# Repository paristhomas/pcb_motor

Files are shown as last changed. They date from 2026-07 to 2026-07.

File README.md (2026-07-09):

# pcb_motor

**Design coreless axial-flux PCB motors — concept to fab-ready Gerbers.**

A coreless axial-flux motor where the stator is a PCB: copper spirals replace wound
wire, the board house replaces the winding shop, and the rotor is disc magnets glued to
a carrier. This repo takes you from "roughly this much torque in roughly this much
space" to a Gerber zip you can upload to a fab — via an analytical physics engine, a
production coil-artwork generator, and a report generator.

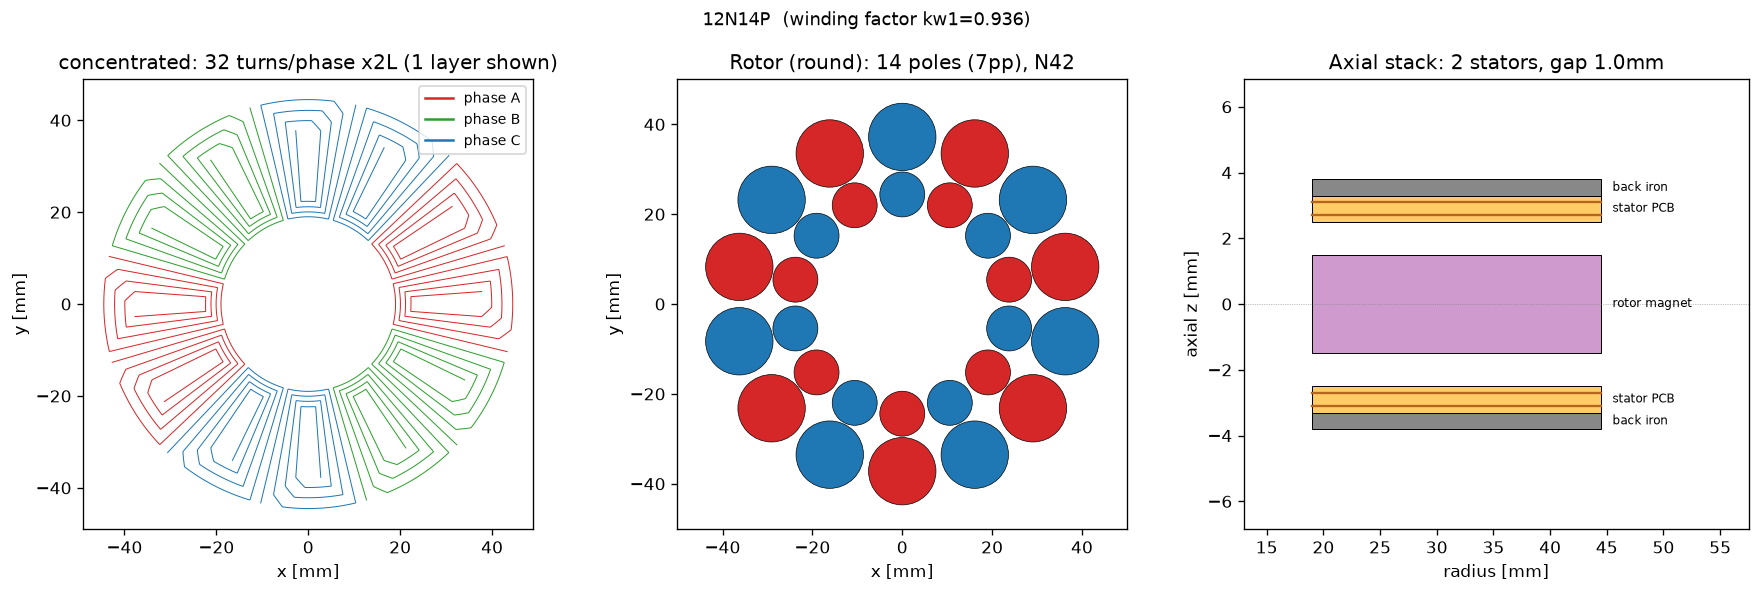
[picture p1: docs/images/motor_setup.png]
Motor setup: winding, rotor, and axial stack


Under the hood: a vectorized Biot–Savart field solver on the actual copper geometry,
Amperian current-loop magnets, proper 3-phase commutation, a coil-artwork generator that
emits production KiCad footprints with net-bearing terminal pads, a board generator that
wraps them into a complete `.kicad_pcb`, and a `kicad-cli` step that plots fab-ready
Gerbers.

## Start here: drive it with an LLM agent

**The intended way to use this repo is to point a coding agent at it and talk to it in
plain language — not to memorize the CLI.** The repo ships a Claude skill
(`.claude/skills/pcb-motor-design`) that turns your requirements into a finished design.

1. Install [Claude Code](https://claude.com/claude-code): `npm i -g @anthropic-ai/claude-code`
   (or use any LLM coding agent — Cursor, the Claude/ChatGPT desktop apps with repo access, etc.).
2. Clone this repo and do the [one-time install](#install) below (`.venv` + `pip install -e .`).
3. From the repo root, launch the agent (`claude`) and just describe the motor you want:

> "design me a pancake motor for a camera gimbal, about 50 mNm continuous, 80 mm max
> diameter, 24 V bus"

The skill auto-loads and the agent captures the requirements, seeds a design, iterates it
against your envelope, runs the feasibility gates, and produces the KiCad files, Gerbers,
and an HTML report — asking you to confirm along the way. You never have to learn the
commands yourself; the agent runs them. [docs/design_guide.md](docs/design_guide.md) is
the full stage-by-stage walkthrough; the rest of this README is the short version for
when you *do* want to drive the CLI by hand.

## Install

```bash
python3 -m venv .venv
.venv/bin/pip install -e ".[dev]"
source .venv/bin/activate
```

Core deps: numpy, scipy, matplotlib, pyyaml, shapely. The optional `[sweep]` extra adds
`holobench` for interactive parameter-sweep dashboards and optuna search. Exporting
Gerbers additionally needs **KiCad ≥ 7** on the machine (the `kicad-cli` it ships); the
tool auto-detects a native install or a Windows KiCad reachable from WSL.

## The five-minute tour

Every design lives in a *session* — a directory under `designs/<name>/` holding the
saved motor plus everything you generate for it. Seed one from defaults (a 60 mm-class
12-slot / 14-pole twin-stator machine) and it evaluates immediately:

```text
$ pcb-motor new --session my-first-motor
session saved to designs/my-first-motor
requirements skeleton written to designs/my-first-motor/requirements.yaml -- fill in your targets (torque, speed, voltage, envelope, duty)
pcb-motor point  [concentrated, 7pp, N42, 2 stator(s)]
--------------------------------------------------------
  Continuous acceleration             583.1 rad/s^2
  Continuous torque                   15.39 mNm
  Kt (torque constant)                48.48 mNm/A
  Continuous current                 0.3175 A
  Mean airgap |Bz|                   0.1823 T
  ...
  Phase inductance (air-core)         76.86 uH
  PWM ripple @bus/fsw                 1.626 A pp
  Ext. L for ripple budget             1235 uH
  ...
  Winding factor kw1                 0.9393

!!!!!!!!!!!!!!!!!!!!!!!!!!!!!!!!!!!!!!!!!!!!!!!!!!!!!!!!
WARNINGS (1):
  ! PWM ripple 1.63 A pp exceeds the 0.10 A budget (17x) at 12 V bus / 24 kHz / 30% of I_cont: not drivable without ~1235 uH/phase external inductance -- see design guide Stage 5.
!!!!!!!!!!!!!!!!!!!!!!!!!!!!!!!!!!!!!!!!!!!!!!!!!!!!!!!!
```

The skeleton `requirements.yaml` holds your torque/speed/voltage/envelope/duty targets,
so the design and its requirements travel together. The wall of exclamation marks is the
no-choke feasibility gate: air-core PCB windings have very little inductance, so most
small designs need a series choke to run from a PWM drive. The gate reports that now
rather than after boards are ordered (design guide Stage 5 is entirely about this).

`--set` overrides any `MotorDesign` field on top of the saved session, and
`pcb-motor fields` prints every settable field, grouped, with its default and meaning:

```text
$ pcb-motor point --session my-first-motor --set trace_width_m=0.2e-3
pcb-motor point  [concentrated, 7pp, N42, 2 stator(s)]
--------------------------------------------------------
  Continuous acceleration             622.8 rad/s^2
  Continuous torque                   16.44 mNm
  ...
```

Then generate the deliverables:

```text
$ pcb-motor report --session my-first-motor
design report written to designs/my-first-motor/design_report.html

$ pcb-motor datasheet --session my-first-motor
datasheet written to designs/my-first-motor/datasheet.md

$ pcb-motor footprint --session my-first-motor
footprint written to designs/my-first-motor/stator_full_2side.kicad_mod (PASS, ...)

$ pcb-motor board --session my-first-motor --gerbers
board written to designs/my-first-motor/kicad_board (PASS)
SUMMARY: PASS  (12 files, zip pcb_motor_stator_gerbers.zip)  kicad-cli 9.0.7
```

`footprint` builds the production two-sided filled-copper stator footprint — net-bearing
terminal pads, via stitch, clearance-verified against JLC rules *before* it writes.
`board` wraps that footprint in a complete `.kicad_pcb` (board outline, bore, WYE nets),
and `--gerbers` plots the fab-ready Gerber + drill set and zips it. For the general
board path the coil copper plots as filled polygons and the cross-ring phase
interconnect is left as a ratsnest for you to route in KiCad — the board is
manufacturable, and that last routing step is the one thing the tool leaves to you.
(The `export` command is a quick `fp_line` artwork preview for eyeballing in KiCad.)

Rounding out the CLI: `config` (setup figure), `showcase` (the shareable single-file
story page — see below), `compare` (sessions side by side), and `sweep` / `optimize`
(interactive dashboards and optuna, with the `[sweep]` extra).

Here's the fabricated 12N14P winding the engine generated, and the Biot–Savart field its
rotor puts through the stator plane:

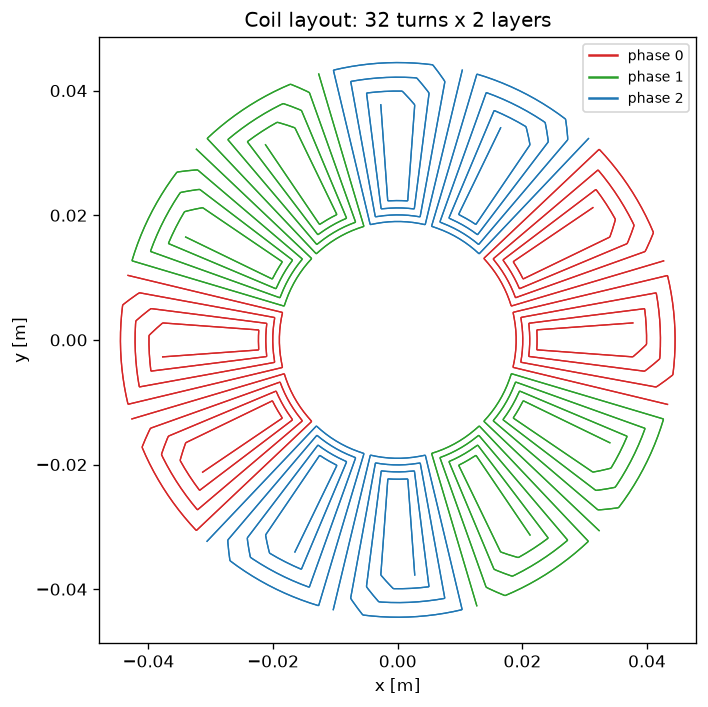
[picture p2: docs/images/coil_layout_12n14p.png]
12N14P coil layout


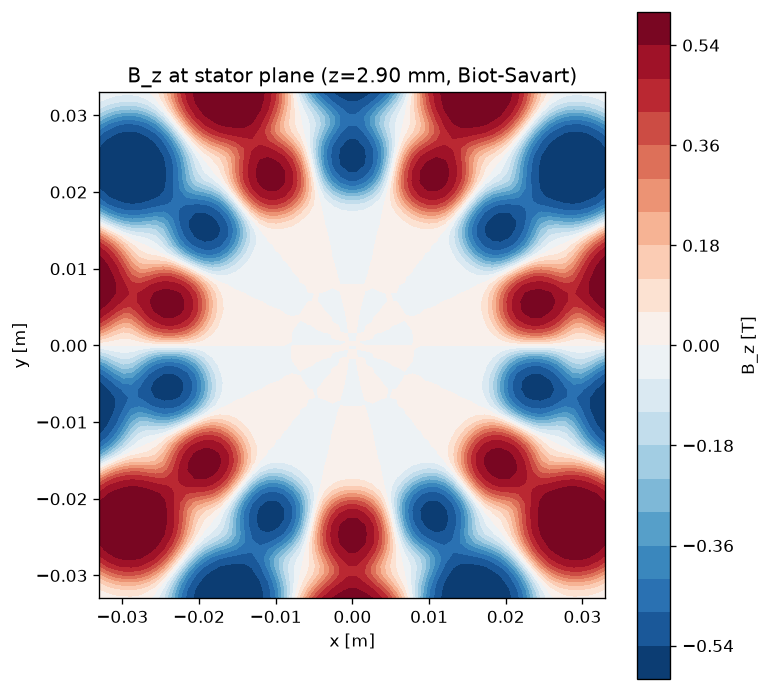
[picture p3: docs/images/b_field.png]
Airgap B_z field at the stator plane


## What you get

- **Coil artwork** — `.kicad_mod` footprints of the real winding. The production builder
  (`pcb_motor.kicad.build_footprint`) emits two-sided filled-copper artwork with
  net-bearing terminal pads, mirrored back-layer copper (so the two layers add torque
  rather than cancel it), a via stitch between layers, and in-footprint series bridges.
  It shapely-verifies every clearance against JLC 1 oz rules before writing and refuses
  to emit a failing board.
- **A complete KiCad board** — `pcb_motor.kicad.build_board` wraps the footprint in a
  full `.kicad_pcb` (board outline, bore, mounting holes, WYE nets bound to the terminal
  pads), alongside the symbol library and pre-wired 3-phase schematic from
  `build_kicad_project`. The fabricated board (dualstator90-12n14p) additionally ships a
  verbatim fully-routed board.
- **Fab-ready Gerbers** — `pcb_motor.kicad.export_gerbers` runs `kicad-cli` to plot the
  standard 2-layer set (copper, mask, silkscreen, paste, edge cuts) plus an Excellon
  drill file, and zips it for upload.
- **An HTML design report and Markdown datasheet** — every headline number plus the
  setup figures and a self-contained showcase page.
- **Honest feasibility numbers** — thermal continuous current, drive voltage at that
  current, current density, airgap shear, rotor inertia, and the no-choke drive gate:
  worst-case PWM current ripple (`v_bus / (4·L·f_pwm)`) and the external inductance
  needed to hit your ripple budget. Most small PCB motors need that choke.

## The main event: the board that was fabricated

[`examples/dualstator90-12n14p/`](examples/dualstator90-12n14p/) (shipped as *gimbal90*) is
a real 90 mm 12N14P dual-stator stator that was **actually fabricated** — this is the
board the whole repo exists to reproduce. It is a fully-routed board (every coil link, WYE
star and phase lead baked into copper), with back iron, M3 mounting tabs and PTH terminals.
`pcb-motor board --session dualstator90-12n14p --gerbers` regenerates it and plots its
Gerbers; the regenerated board is coordinate-for-coordinate identical to the manufactured
one in [`examples/dualstator90-12n14p/fabricated/`](examples/dualstator90-12n14p/fabricated/)
and the Gerbers match it layer-for-layer (see `tests/test_board_fabequiv.py`).

The best way to meet it is the **showcase report** — one self-contained HTML page from
`pcb-motor showcase`: the rotor spinning over the real copper with the Biot–Savart field,
the zoomable board artwork with its real outline and mounting tabs, the exploded stack, the
trace-width trade charts, and the drive-gate verdict in large print.

## Generalization evals (proof it isn't over-fit to that one board)

Two further sessions exist only to show the same concept→board→Gerber workflow holds for
*different* machines, driven the same way:

- [`examples/dualstator80-36n42p/`](examples/dualstator80-36n42p/) — an 80 mm, 42-pole
  dual-stator pancake (off-the-shelf round disc magnets). The tool's honest verdict:
  **20.5 mNm continuous (±30%)**, and *driving it choke-free from an ODrive is infeasible by
  32× — budget ~204 µH per phase.* It reports the "no" instead of hiding it.
- [`examples/dualstator140-24n28p/`](examples/dualstator140-24n28p/) — a 140 mm 24N28P
  machine an **independent agent** designed end-to-end from only a brief and the skill.

## The physics, honestly

> This is an **analytical, feasibility-grade model: treat absolute torque as ±30%.**
> The field solver itself is validated to <1% against closed-form solutions — the error
> budget is dominated by what the model *doesn't* capture: magnet Br tolerance and
> fringing, your actual assembled air gap (the single most sensitive parameter, and the
> one your 3D-printed parts control), and etching/plating variation in the copper.
> Relative comparisons between designs are much better than ±30%. Calibrate against FEMM
> or a bench coil before you commit money to a build. Details and validation notes in
> [docs/physics.md](docs/physics.md).

Limitations, stated up front:

- **No magnetic saturation modeling.** Fine for coreless (air doesn't saturate); the
  optional back-iron model is method-of-images with µ→∞ plates — a *sanity flag*, not a
  design tool, and it ignores eddy/hysteresis drag in the plate.
- **Thermal model is a lumped convection balance** (`h·A·ΔT`) with an assumed film
  coefficient — good for "is this thermally plausible", not for hot-spot prediction.
- **Inductance is ±20%** (Neumann double sum) — right for "do I need a choke", wrong for
  filter design.
- **Dual-rotor axial attraction is reported as a warning, not a number.** Two magnet
  disks facing each other pull hard; size the spacer, hub, and assembly jig for it.
- No cogging (coreless — there is none), no acoustic, no bearing model, no FEA.

## Docs

- [docs/design_guide.md](docs/design_guide.md) — the full walkthrough: requirements →
  seed → evaluate → iterate → feasibility gate → KiCad board → Gerbers → fab notes.
- [docs/physics.md](docs/physics.md) — how the model works and where it approximates.
- [docs/jlc_design_rules.md](docs/jlc_design_rules.md) — JLCPCB rules and IPC
  current-capacity numbers the coil generator designs against.

Housekeeping: `designs/` is a working area (gitignored) where your sessions land;
`examples/` holds the committed, published designs.

## Acknowledgements

The Biot–Savart field solver (`pcb_motor/field.py`) is an independent NumPy
reimplementation cross-validated against the "Biot-Savart Magnetic Field Calculator" by
Mingde Yin and Ryan Zazo.

## License

MIT — see [LICENSE](LICENSE).

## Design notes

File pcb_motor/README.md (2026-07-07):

# pcb_motor — Biot–Savart coreless axial-flux PCB-motor engine

For a given stator/rotor configuration, evaluate (and optimise) the PCB
stator-coil design directly from copper geometry, *simulating* the magnetics
numerically (Biot–Savart). Reports Kt, torque, air-gap field, winding factor,
thermal continuous rating, current density, shear, rotor inertia, and
continuous acceleration `a_cont = τ_cont / J` — enough to judge a design against
real requirements (torque, voltage, size, duty), not just one objective.

Self-contained: all physical constants live in `constants.py`.

## Install / run

```bash
python3 -m venv .venv && .venv/bin/pip install -e ".[dev]"
.venv/bin/python -m pcb_motor point                       # evaluate one design
.venv/bin/python -m pcb_motor config --out setup.png      # winding + rotor + stack figure
.venv/bin/python -m pcb_motor sweep --inputs trace_width_mm,trace_space_mm --serve
.venv/bin/python -m pcb_motor optimize --trials 100       # max continuous accel
.venv/bin/python -m pytest -q
```
`point` needs only the core deps; `sweep`/`optimize` need `holobench`
(`pip install -e ".[sweep]"`).

## Model (and its limits — this is a ~±30% feasibility-grade model)

- **Field** (`field.py`): vectorised numpy Biot–Savart kernel. Validated to <1%
  against the closed-form on-axis loop field (`tests/test_field.py`).
- **Magnets** (`magnets.py`): Amperian current-loop model, `I_eq = (Br/μ0)·t`,
  alternating polarity. Rotor topologies via `magnet_topology`:
  `"arc"` (continuous pole-arc ring); `"round"` (two concentric rings of round
  disc magnets — inner+outer of each pole share polarity; the buildable round-stock
  rotor); and the single-ring study variants `"round_outer"` (outer ring of larger
  discs only) and `"round_inner"` (inner ring of smaller discs only). Inertia
  (`inertia.py`) and the carrier extent are topology-aware (they key off
  `magnets.active_rings`), so the acceleration objective fairly reflects each
  rotor's magnet mass. Perimeter/thin-shell approximation.
- **Coils** (`coils.py`): default **`concentrated`** — `n_slots` discrete
  multi-turn **wedge-spiral** coils (default 12 slots / 14 poles = 12N14P). Turns
  nest inward by one trace pitch on all sides, so no copper overlaps (fabricable,
  KiCad-exportable). Phase + polarity per tooth come from the **star-of-slots**
  layout (12N14P: order A,C,B in opposite-polarity pairs). `winding_factor()`
  returns kw1 (~0.93 for 12N14P). Alternatives: `radial_spoke`, `spiral`.
- **Torque** (`torque.py`): field evaluated on a coarse polar grid per rotor
  angle/layer and interpolated onto the coil (decouples cost from mesh density).
  Kt uses **proper 3-phase commutation** — sinusoidal currents synchronised to the
  rotor at the optimal commutation angle — so the **winding factor is folded into
  Kt physically** (no hand-applied kw). Reports `winding_factor` (analytic kw1) and
  `winding_utilisation` (commutated/ideal-abs-sum).
- **Back iron** (`iron.py`): optional flat plate behind each stator, modelled by
  the method of images (μ→∞ planes). Sanity-grade: no saturation, no plate
  eddy/hysteresis drag; the per-plate magnetic pull is reported so the mechanics
  can be sized for it.
- **Continuous torque/accel**: `τ_cont = Kt·I_cont`, `I_cont` from the thermal
  model (`thermal.py`), `J` from `inertia.py`.
- **Parasitics** (`parasitics.py`): air-core phase inductance (Neumann double
  sum, ~±20%), worst-case (D=0.5) PWM current ripple
  `ripple_pp = v_bus/(4·L·f_pwm)` — the "do I need a choke" feasibility gate —
  and an eddy-loss screen for wide traces at speed.

Key caveat: `current_density` is reported as a sanity flag, not enforced, and
absolute numbers everywhere are feasibility-grade (~±30%), never bench-exact.

## Exploring the design space

Sweep any 1–3 `MotorDesign` axes interactively (needs `holobench`); open the
printed `http://localhost:9001`:

```bash
.venv/bin/python -m pcb_motor sweep \
  --inputs trace_width_mm,magnet_topology \
  --results accel_cont,tau_cont,kt,j_rotor,b_gap_mean,copper_mass \
  --serve --port 9001
```

Key reading: `accel_cont` is magnet-fill-insensitive on a bare rotor (torque and
inertia both scale with magnet mass and cancel); compare rotors on `kt` /
`tau_cont` / `b_gap_mean`, or on acceleration *with a load inertia*
(`--set load_inertia_kgm2=…`).

## Layout
`design.py` (contracts) · `field.py` · `magnets.py` · `coils.py` · `torque.py` ·
`iron.py` · `parasitics.py` · `thermal.py` · `inertia.py` · `evaluate.py`
(design→results) · `sweep.py` (bencher) · `viz.py` · `cli.py` · `kicad/`
(footprint/project export). See `interfaces.md` for the module APIs.

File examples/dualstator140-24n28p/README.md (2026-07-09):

# dualstator140-24n28p — the generalization eval (designed by an independent agent)

This design exists to answer one question: **is the `pcb_motor` workflow actually
general, or is it secretly tuned for the dualstator90-12n14p board it was built around?**

To test that honestly, a **fresh agent** — given only an application brief, this repo,
and the `pcb-motor-design` skill, and *none* of the authoring context — drove the entire
workflow itself, in one shot, on the first run, with zero tool fixes. What's here is what
it produced, **untouched except for one later change made at the maintainer's explicit
request: a third magnet ring** (see "Maintainer enhancement" below). Everything else —
the 24N28P winding, the board, the Gerbers, the honest gate failure — is exactly the
agent's one-shot output.

## The brief it was given

> A pancake BLDC motor for a lightweight camera slider / pan-head direct drive.
> Outer diameter ≤ 140 mm, thin stack; maximize continuous torque at the thermal limit
> (40–60 mNm would be great); ODrive, 24 V bus; dual-stator / single-rotor, no back iron;
> two 2-layer 0.8 mm FR4 JLCPCB boards (1 oz, 5/5 mil); off-the-shelf round disc magnets.

## What the agent chose (and why)

- **24N28P** (24 slots, 14 pole-pairs), verified **kw1 = 0.9374** — a genuinely different
  machine from dualstator90-12n14p (12N14P, 90 mm). It compared three pole counts head-to-head and
  found that with *round-disc* magnets the largest combo (36N42P) is actually the worst,
  because disc packing forces smaller magnets and collapses the airgap field — the round
  magnet constraint inverts the usual "more poles → more torque" intuition.
- **134 mm copper OD** (138 mm board edge, inside the 140 mm limit), 60 mm bore, N52 discs
  in **two concentric rings**, tapered-wedge traces, 0.6 mm neck / 0.127 mm space.

## Maintainer enhancement — a third magnet ring

The agent shipped a **two-ring** rotor (that is what the eval recorded). Afterwards, at
the maintainer's explicit request, this repo grew a general `round3` topology (a middle
ring of discs per pole) and applied it here — **the single deviation from the agent's
one-shot design.** The three rings step **up in size going outward** — inner **Ø8 @ 40 mm**,
middle **Ø9 @ 49.5 mm**, outer **Ø12 @ 61 mm** (the outer ring nudged out from the agent's
58 mm to make room, its edge now at the 67 mm coil OD). Filling the previously-empty middle
band — full of current-carrying copper but no field — lifts continuous torque **+32.6%**
(142 → **188 mN·m**, Kt 97 → **129 mN·m/A**) for the same winding, current and copper. Every
disc keeps **≥0.8 mm of carrier** to its neighbours (tightest is the inner ring at 0.98 mm
pole-to-pole; the engine warns below 0.8 mm). This is a *documented change to the artifact*,
not part of the blind eval; the two-ring numbers above are what the agent produced on its own.

## What it delivered (all PASS)

| Artifact | File |
|---|---|
| Production footprint (clearance-verified) | `stator_full_2side.kicad_mod` |
| Complete board | `kicad_board/pcb_motor_stator.kicad_pcb` |
| Fab-ready Gerbers (12 files + drill) | `kicad_board/pcb_motor_stator_gerbers.zip` |
| Showcase report | `report.html` |
| Datasheet / design | `datasheet.md`, `motor.json`, `requirements.yaml` |

Headline numbers (analytical, **±30%** — calibrate against FEMM / a bench coil before
spending money), **with the three-ring rotor**: **Kt ≈ 129 mNm/A, ~188 mNm continuous**
at 1.46 A / 6.0 Ω, drive voltage 11.6 V (comfortable under the 24 V bus), kw1 0.9374,
airgap |Bz| ≈ 0.13 T. (The agent's original two-ring rotor: Kt ≈ 97 mNm/A, ~142 mNm,
|Bz| ≈ 0.10 T.)

## The honest verdict

The no-choke drive gate **fails, on purpose and out loud**: 7.2 A pp ripple vs a 0.44 A
budget — **16× over** at 24 V / 24 kHz. Air-core PCB windings are µH-class (L ≈ 35 µH), so
this needs a **~536 µH/phase series choke** (rated ≥ 1.5 A) to run from a bare ODrive.
The agent reported this rather than dialling knobs to fake a pass — which is exactly the
behaviour the tool is built to produce.

As with the general board path, the cross-ring phase interconnect (9 joins) is left as a
**ratsnest** for a human to route in KiCad; the board is otherwise complete and
manufacturable.

**Bottom line:** an independent agent took the workflow from a bare application brief to
a fab-ready board + Gerbers + report, on the first run, with no author intervention. The
workflow generalizes.

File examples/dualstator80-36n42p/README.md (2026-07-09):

# dualstator80-36n42p — an 80 mm no-choke attempt, honestly lost

This directory is a complete, committed design session: what the tool was asked for,
what it designed, and what it said about the result — including the part the brief
didn't want to hear. Everything here was produced by `pcb-motor` commands against
this repo; nothing is retouched. All absolute numbers carry the model's honesty band:
**±30% on torque** (see [docs/physics.md](../../docs/physics.md)).

## The brief

From [`requirements.yaml`](requirements.yaml): a flat pancake motor, **80 mm outer
diameter hard limit**, driven by an ODrive, **no external inductors/chokes if
possible**, maximize continuous torque. Fixed by the customer: 21 pole pairs
(→ the verified 36N42P combo), two stators in series (one PCB each side of a single
rotor disk), 2 copper layers per board, 0.8 mm FR4, 1 oz copper (JLC 5/5 mil),
1.0 mm air gap per side, no iron anywhere. Magnet stock: **off-the-shelf round disc
magnets only** — real sizes Ø3/Ø4/Ø5/Ø6 mm, N52.

## The design hunt, condensed

**Magnet ring geometry.** With `magnet_topology=round`, 42 poles have to fit around
a ring inside a 40 mm radius board. The packing that won: **42× Ø5×3 mm N52 discs at
r = 35 mm** (outer ring) plus **42× Ø4×3 mm at r = 29 mm** (inner ring), one disc pair
per pole. At r = 35 mm the pole pitch is 5.24 mm, so adjacent Ø5 discs sit ~0.24 mm
apart — the model is perfectly happy with that; your 3D printer is not. Print the
carrier with open-walled pockets (adjacent discs repel, and that repulsion holds each
disc against its pocket rim) or accept a coarser packing. The design guide now has a
section on exactly this.

**Copper annulus tracking.** Torque comes from radial copper sitting under the
magnets, so the active annulus was moved out to track the disc rings:
`r_inner=25 mm`, `r_outer=38 mm` (the discs span ~27–37.5 mm). Copper inside r = 25 mm
was doing nothing but adding resistance.

**The trace-width trade.** This is where the no-choke hope went to die, with numbers.
Inductance grows ~N² while torque-per-ohm falls, so we swept trace width both ways
([`compare.md`](compare.md) has the head-to-head):

| | `dualstator80-36n42p` (0.50 mm traces) | `dualstator80-36n42p-maxL` (0.127 mm traces) |
|---|---|---|
| Kt | 20.75 mNm/A | 48.97 mNm/A |
| Continuous torque | **20.52 mNm** | 16.15 mNm |
| R (total, series) | 3.0 Ω | 27.0 Ω |
| L (total, series) | 6.7 µH | 45.5 µH |
| Choke still needed | 204 µH/phase | 586 µH/phase |

Even maxing out turns at the fab's minimum trace width — a 7× inductance gain, paid
for with a quarter of the continuous torque — leaves the winding an order of
magnitude short of choke-free. So the committed design takes the torque.

## What the tool told us

The saved design ([`motor.json`](motor.json), full numbers in
[`datasheet.md`](datasheet.md)): **Kt 20.75 mNm/A, 20.5 mNm continuous (±30%) at
0.99 A**, R 3.0 Ω and L 6.7 µH (totals for both boards in series), kw1 0.943,
3.9 V drive voltage at continuous current. And the verdict, verbatim from
`pcb-motor point --session dualstator80-36n42p` at the most favorable ODrive operating point
(12 V bus, 48 kHz PWM — i.e. an ODrive Pro/S1; a stock v3.6 at 24 kHz doubles the
ripple):

```text
!!!!!!!!!!!!!!!!!!!!!!!!!!!!!!!!!!!!!!!!!!!!!!!!!!!!!!!!
WARNINGS (1):
  ! PWM ripple 9.35 A pp exceeds the 0.30 A budget (32x) at 12 V bus / 48 kHz / 30% of I_cont: not drivable without ~204 uH/phase external inductance -- see design guide Stage 5.
!!!!!!!!!!!!!!!!!!!!!!!!!!!!!!!!!!!!!!!!!!!!!!!!!!!!!!!!
```

**The no-choke brief is infeasible, by 32×.** Not marginal, not fixable with a knob:
9.35 A pp of PWM ripple on a motor rated for 0.99 A continuous. At 24 V / 24 kHz
(stock v3.6 territory) the requirement grows to ~836 µH/phase. The honest answer is
three chokes:

> **Choke shopping spec:** ≥ 204 µH per phase at 12 V / 48 kHz → buy **220–330 µH
> shielded drum-core power inductors, I_sat ≥ 1.5 A, DCR ≤ 0.3 Ω** — Bourns SRR1260
> class, three of them, one in series with each phase lead.

## The deliverables

- [`datasheet.md`](datasheet.md) — every headline number, including the explicit
  PWM-ripple gate rows (bare-winding ripple, FAIL, required choke).
- [`stator_full_2side.kicad_mod`](stator_full_2side.kicad_mod) — the production
  two-sided filled-copper stator footprint, tapered 0.50 mm traces at 0.127 mm space,
  **clearance-verified before writing: PASS, worst clearance 0.1365 mm against the
  0.127 mm JLC 1 oz rule**.
- [`kicad/`](kicad/) — the complete KiCad project: single stator symbol, WYE
  pre-wired schematic, library tables, and the footprint vendored as
  `pcb_motor.pretty/coil_full_2side.kicad_mod`. Order two boards; wire them in
  **series** (never parallel — Stage 5 of the design guide says why).
- [`setup.png`](setup.png) — winding, rotor, and axial stack figure.
- [`compare.md`](compare.md) — the trace-width trade study above.

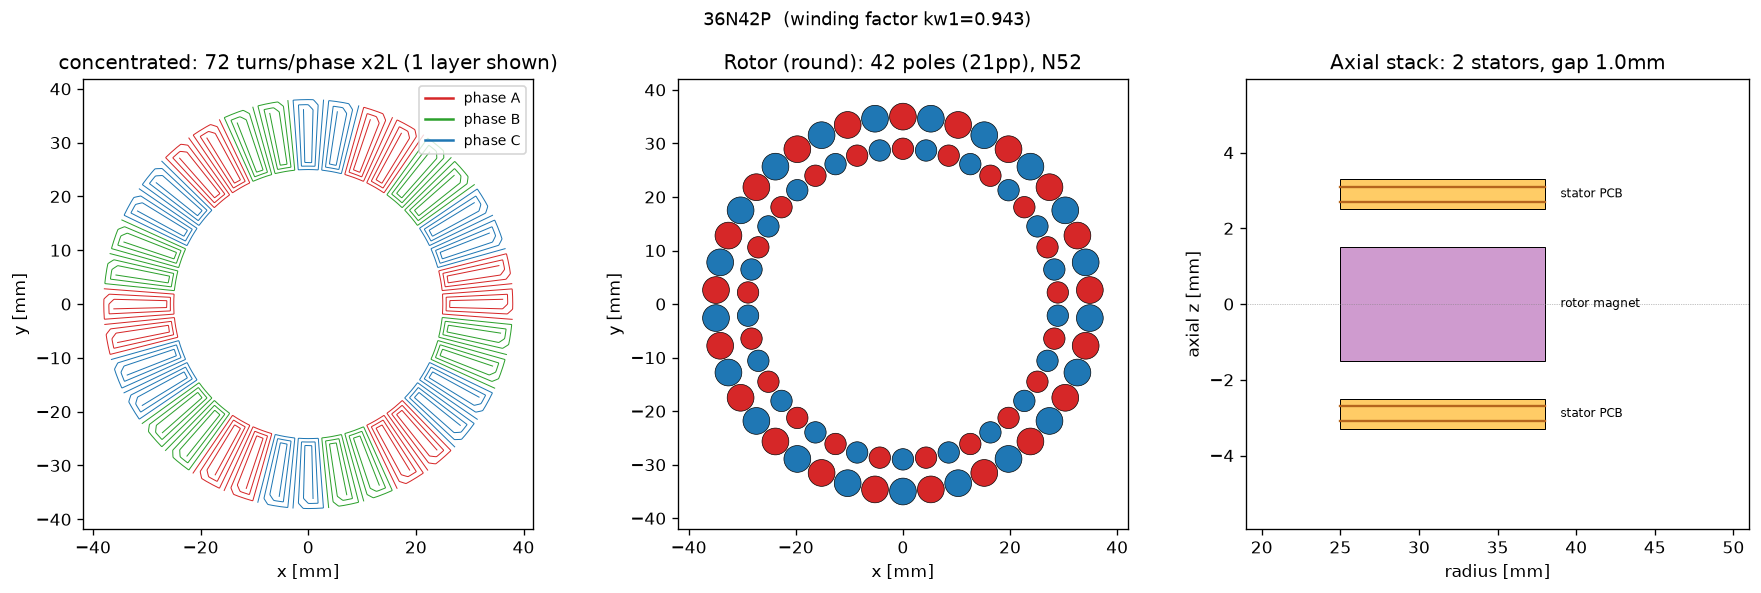
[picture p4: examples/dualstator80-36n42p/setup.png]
The dualstator80-36n42p winding, rotor and stack


## Reproduce / iterate it

Sessions live under `designs/` (gitignored working area). To pick this design up:

```bash
mkdir -p designs/dualstator80-36n42p
cp examples/dualstator80-36n42p/motor.json examples/dualstator80-36n42p/requirements.yaml designs/dualstator80-36n42p/
.venv/bin/pcb-motor point --session dualstator80-36n42p          # re-evaluate (~30-60 s)
.venv/bin/pcb-motor footprint --session dualstator80-36n42p --project   # rebuild the KiCad artifacts
```

Every number above is the analytical model talking. Before spending real money:
measure the as-built air gap, bench-check Kt, and read
[docs/physics.md](../../docs/physics.md) for exactly which corners the model cuts.

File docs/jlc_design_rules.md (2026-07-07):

# JLCPCB design rules + trace current capacity

The fab limits the coil generator designs against, with the IPC current-capacity
numbers you'll want when sanity-checking a winding. **Process scope:** JLCPCB standard
FR-4, **1–2 layer**, standard process unless noted.

> Vendor capabilities change over time. Numbers below were compiled 2026-06-19 from
> the sources cited at the bottom (reflecting late-2025 JLCPCB capability sheets).
> **Re-confirm critical numbers on JLCPCB's live capabilities page / instant-quote DRC
> before committing a design.** The current-capacity tables are IPC estimates, not
> vendor guarantees.

These constants are baked into the tooling where they're structural: the production
footprint builder (`pcb_motor/kicad/footprint.py`) uses the 1 oz trace floor
(0.127 mm) and the 0.30/0.60 mm via, and verifies your `trace_space_m` as the
clearance gate before writing anything.

## 1. Min trace width and spacing (1–2 layer)

| Outer copper | Min trace width | Min trace spacing |
|---|---|---|
| **1 oz (35 µm)** | **5 mil (0.127 mm)** | **5 mil (0.127 mm)** |
| **2 oz (70 µm)** | **8 mil (0.20 mm)** | **8 mil (0.20 mm)** |

- The 5 mil / 5 mil figure is JLCPCB's 1–2-layer standard-process limit. JLC
  *recommends* 6 mil / 6 mil for margin; 4-layer standard goes to 3.5 mil.
- **2 oz needs wider trace/space** because thicker copper etches with more undercut —
  the limit roughly increases from 5 mil to **8 mil** for both width and gap. (Some
  summaries quote 7 mil; treat 8 mil / 0.20 mm as the safe design target.)
- Design consequence for coils: switching a design from 1 oz to 2 oz is **not** free —
  a 0.13–0.15 mm-spaced winding must be re-spaced to ≥ 0.20 mm, which costs turns.
  Set `trace_space_m` to the copper weight you're actually ordering.

## 2. Min via (drill, diameter, annular ring)

| Tier | Min drill (hole) | Min via diameter (pad) | Min annular ring |
|---|---|---|---|
| **Standard, 2-layer** | **0.3 mm (12 mil)** | **0.6 mm (24 mil)** *(some sheets 0.45 mm)* | 0.15 mm (6 mil), 0.2 mm recommended |
| **Advanced / extra-cost** | **0.2 mm** mechanical (down to **0.15 mm** with resin-plug / laser) | **0.35–0.45 mm** | 0.13–0.15 mm |

- Holes **< 0.3 mm are "small holes"** and typically incur extra cost / advanced
  process.
- Min PTH (plated through-hole) = **0.15 mm**.
- Rule used by JLC: **pad ≥ drill + 0.3 mm** (i.e. 0.15 mm ring per side) for safe
  registration. The footprint builder's stitch vias are 0.30 mm drill / 0.60 mm pad.

## 3. Current-carrying capacity — IPC (external / outer-layer traces)

**Formula (IPC-2221 external constant, conservative):**

```
I = k · ΔT^0.44 · A^0.725
  I  = continuous current [A]
  ΔT = allowed temperature rise above ambient [°C]
  A  = trace cross-section [mil²]  = width × copper thickness
  k  = 0.048  (external/outer layer; inner layers use 0.024)
  thickness: 1 oz = 35 µm = 1.378 mil ; 2 oz = 70 µm = 2.756 mil
```

> IPC-2221 (k=0.048) is the **conservative** classic curve. IPC-2152 (the newer
> standard, based on direct measurement) generally allows **higher** current for the
> same trace in still air — the values below are a safe lower bound; treat real
> headroom as ≥ these numbers.

**Continuous current vs. trace width (external trace):**

| Width | 1 oz @ 10 °C | 1 oz @ 20 °C | 2 oz @ 10 °C | 2 oz @ 20 °C |
|---|---|---|---|---|
| 0.20 mm | 0.74 A | 1.01 A | 1.23 A | 1.67 A |
| 0.50 mm | 1.45 A | 1.96 A | 2.39 A | 3.24 A |
| 0.90 mm | 2.22 A | 3.01 A | 3.66 A | 4.97 A |
| 1.00 mm | 2.39 A | 3.24 A | 3.95 A | 5.36 A |
| 1.50 mm | 3.21 A | 4.35 A | 5.30 A | 7.20 A |
| 2.00 mm | 3.95 A | 5.36 A | 6.53 A | 8.86 A |
| 2.30 mm | 4.37 A | 5.93 A | 7.23 A | 9.81 A |
| 3.00 mm | 5.30 A | 7.20 A | 8.77 A | 11.89 A |

**Rule-of-thumb (A per mm of width).** Capacity scales as width^0.725, so A/mm is
*not* constant — it is higher for narrow traces. Quoted at ~1 mm width:

| | @ 10 °C rise | @ 20 °C rise |
|---|---|---|
| **1 oz** | **≈ 2.4 A/mm** | **≈ 3.2 A/mm** |
| **2 oz** | **≈ 3.9 A/mm** | **≈ 5.4 A/mm** |

(For pours/very wide copper the effective A/mm is somewhat lower; for sub-0.5 mm
traces it is higher.)

How to read this for a tapered winding: the constraint is the **narrowest neck**, at
`r_inner`. Worked example: a tapered coil running 0.9–2.3 mm wide at 1 oz carries
≈ 2.2 A continuous at a ~10 °C local rise at its 0.9 mm neck (≈ 3.0 A at 20 °C) —
comfortably wider everywhere else. The same geometry at 2 oz carries ≈ 1.65× more, but
must be re-spaced per §1. Note this local-rise check is *separate from* the
whole-board thermal model in `thermal.py` — a winding can pass the board-level balance
and still have a warm neck; check both.

## 4. Via current capacity

Plated barrel modeled as an annular conductor (copper plating ≈ 20–25 µm wall),
IPC-2221 external:

| Via drill | Plating | @ 10 °C rise | @ 20 °C rise |
|---|---|---|---|
| **0.3 mm** | 20–25 µm | **≈ 1.5–1.8 A** | **≈ 2.1–2.4 A** |
| **0.4 mm** | 20–25 µm | **≈ 1.9–2.2 A** | **≈ 2.6–3.0 A** |

**Vias to carry a current (rule of thumb):** budget **~1–1.5 A per 0.3 mm via**
continuous for a comfortable margin — e.g. to carry ~2 A of phase current through a
layer transition, use 2 vias, 3 for healthy headroom/redundancy. This is why the
footprint builder stitches each coil's layer transition with a *farm* of vias rather
than one.

## 5. Other relevant JLC notes

- **Outer copper options:** 1 oz (35 µm, standard/low-cost default) or **2 oz
  (70 µm)** at extra cost; 2-layer can go heavier (up to ~4.5 oz) at further cost.
  Inner layers offer 0.5 oz.
- **Min hole:** PTH 0.15 mm; mechanical small-hole penalty below 0.3 mm.
- **Board thickness:** 0.4–2.0 mm range; 1.6 mm standard. Tolerance ≈ **±10%** of
  finished thickness — remember the board is inside your magnetic gap.
- **Finished copper tolerance:** plated copper adds to base foil, so a "1 oz" outer
  layer finishes ≈ 35 µm + plating; traces etch slightly narrow vs. drawn (undercut),
  more so at 2 oz — keep the 5→8 mil min-width margin in mind.

## Sources (fetched 2026-06-19)

- JLCPCB — *PCB Capabilities* and FR-4 capability sheet: <https://jlcpcb.com/capabilities/pcb-capabilities>
- JLCPCB — *Copper Weight (Thickness) Guide*: <https://jlcpcb.com/help/article/jlcpcb-copper-weight>
- JLCPCB — *Guide to PCB Via Design*: <https://jlcpcb.com/blog/pcb-via-design-best-practices>
- JLCPCB Q&A — *minimum via size vs. minimum annular ring*: <https://jlcpcb.com/help/answers/detail/110-minimum%20via%20size%20vs.%20minimum%20annular%20ring%20size>
- Schemalyzer — *JLCPCB Design Rules and Capabilities: Complete Specification Guide (2025)* (doc dated 2025-12-05): <https://www.schemalyzer.com/en/blog/manufacturing/jlcpcb/jlcpcb-design-rules>
- BrainVoyage — *JLCPCB Trace Width / Design Rules guides (2024)*: <https://brainvoyage.blog/jlcpcb-trace-width-rules>
- Standards: IPC-2221 (trace current, conservative external k=0.048) and IPC-2152
  (measurement-based, higher allowance).

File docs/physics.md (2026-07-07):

# How the model works (and where it lies)

pcb_motor is an **analytical Biot–Savart model**: it computes fields and torque
directly from the actual copper and magnet geometry, with essentially no empirical
fudge factors. That buys you a model that responds *correctly in shape* to every knob
(radius, turns, gap, poles) — and it's why we can be specific about where the absolute
numbers go wrong. Read this before trusting a number with money.

Everything below lives in a module you can read in one sitting; file names in
parentheses.

## The field solver (`field.py`)

One kernel does all the magnetics: given a `CurrentSource` (a polyline of vertices
with a current per segment), subdivide every segment to `resolution_m` (default
0.5 mm), then for each observation point sum the Biot–Savart contribution
`µ0/4π · I dl × r̂ / |r|²` over all sub-segments — fully vectorized in numpy, so a
whole stator plane is one array operation, not a loop.

**Validation:** against the closed-form on-axis field of a circular loop,
`Bz = µ0 I R² / 2(R² + z²)^{3/2}`, the solver agrees to **<1%** on and off the loop
plane (`tests/test_field.py`). Superposition and current-linearity are also asserted.
The numerics are not where the ±30% comes from.

## Magnets as bound currents (`magnets.py`)

A uniformly-magnetized magnet is exactly equivalent to a surface (Amperian) current
around its perimeter: `I_eq = (Br/µ0) · thickness`. So the rotor becomes a set of
current loops at the magnet mid-plane — one loop per pole, alternating sign — and the
same field kernel solves them. Two rotor shapes are modeled:

- **`arc`** — continuous pole-arc segments (annular wedges, `pole_coverage` of each
  pole pitch), the classic custom-magnet rotor.
- **`round`** — two concentric rings of round disc magnets (inner + outer disc of each
  pole share polarity): the rotor you can build from stock magnets today.

The loop current can be split across `n_stack` sub-loops through the magnet thickness
for near-field accuracy. `rotor_sides=2` (dual-rotor sandwich) adds a second magnet
plane, same magnetization pattern, on the far side of the stator — the attracting
arrangement, so the axial fields *add* at the copper (asserted to ~2× in
`tests/test_dual_rotor.py`).

What's idealized: perfectly uniform magnetization at nominal Br, sharp pole
transitions, no demagnetization, no temperature coefficient on the magnets.

## The winding (`coils.py`, `coil_spiral.py`)

The default `concentrated` topology generates `n_slots` wedge-shaped multi-turn
spiral coils; turns nest inward by one trace pitch so nothing overlaps — the
simulated geometry is the same geometry that gets exported to KiCad. Phase and
polarity per tooth come from a verified **star-of-slots** table (the 12N14P family
and its 36N42P tiling); anything else falls back to round-robin, which can produce a
winding factor near zero — see the design guide's Stage 4 for the numbers and the
check to run.

Each coil is discretized into segments carrying `phase`, `direction`, and an
`is_radial` flag (torque-producing radial run vs end-turn arc). Two-layer boards
place the back layer as the **mirror** of the front about each coil's radial
centre-line, in series — more on why below.

## Torque and Kt (`torque.py`)

Brute-force field evaluation at every coil segment would be wasteful (the coil mesh
is dense; the field is smooth), so per rotor angle the magnet field is computed on a
coarse polar grid at each copper layer's z-plane and interpolated onto the segment
midpoints. Torque cost is then independent of coil mesh density.

Per segment: Lorentz force `dF = I (dL × B)`, axial torque `(r × dF)_z`. Torque is
linear in phase currents, so it collapses to a per-phase torque vector `G(θ)`; the
evaluator sweeps rotor angles over one electrical period, drives the three phases
with sinusoidal currents at the optimal commutation angle, and reports the mean
torque per ampere as **Kt**.

Two properties worth internalizing:

- **The winding factor is never applied by hand.** kw1 emerges physically from the
  commutated sum over conductors at their actual electrical angles. The analytic kw1
  is *also* computed (`winding_factor()`), but only as a diagnostic — if the two
  disagree, the geometry, not the formula, wins.
- **Only B_z makes torque here.** With radial current sheets, `J × B` gives axial
  torque only through the axial field component (`τ_z ∝ -r·J_r·B_z`); B_r and B_φ are
  integrated too but contribute zero shaft torque for planar radial conductors —
  asserted in `tests/test_torque.py::test_torque_comes_from_axial_field`. This is why
  the B_z map is the field picture worth staring at.

### The mirrored-layer war story

The most instructive bug this project ever produced: the first two-sided coil
generator placed the back copper as a plain copy of the front (what you'd sketch on a
whiteboard). Perfectly plausible-looking board. The torque integrator scored the
front+back series pair at **exactly 0.00** — each turn's return path cancelled its
own torque. Mirroring the back layer about the coil's radial centre-line scored
**+2.00** (same units, same current): layers in series, torque additive. The
production footprint builder inherits this as a hard invariant, and it's the reason
"just simplify the layer mirroring" appears in no roadmap. If you generate your own
two-layer artwork: mirror it, then *check the torque*, because the wrong version
looks identical.

## Thermal limit (`thermal.py`)

Continuous current comes from a lumped steady-state convection balance:

```
P_max  = h_conv · A_cooled · (T_limit − T_ambient)
A      = cooled_faces · π(r_outer² − r_inner²)
I_cont = sqrt(P_max / (loss_phase_factor · R_phase_hot))
```

with copper resistance taken at the hot temperature (+0.39%/K). This is deliberately
crude: one node, no radiation, no conduction into the mount, film coefficient
`h_conv` guessed (15 W/m²K ≈ still air). It answers "is this thermally plausible",
not "where is the hot spot". A fan, a metal mount, or a thermal camera will each
falsify it in your favor or against.

## Inductance, PWM ripple, eddy loss (`parasitics.py`)

**Phase inductance** is a Neumann double sum over one phase's discretized conductor —
mutual terms between every segment pair, with a regularized kernel using the
rectangular-conductor geometric mean distance `0.2235(w+t)` so the self-terms don't
blow up. Air-core only; stated accuracy **±20%**, which is exactly enough for its one
job: the choke question. Like the reported phase resistance, the reported inductance
is the **machine total — all `n_stators` boards in series** (×`n_stators`, ÷`parallel_paths²`);
a per-board bench measurement should read 1/`n_stators` of it.

**PWM ripple** is the worst-case (50% duty) triangle: `ripple_pp = v_bus/(4·L·f_pwm)`,
compared against `drive_ripple_frac · I_cont`; the report includes the external series
inductance needed to hit the budget. This gate is load-bearing — see design guide
Stage 5.

**Eddy loss** in the (wide) traces uses the thin-strip lamination formula
`P/V = π²f²B²w²/(6ρ)` with the local tapered width — an order-of-magnitude screen
that flags high-speed designs, not a loss model.

## Rotor inertia (`inertia.py`)

Magnet ring plus printed carrier, topology-aware (round-disc rotors count their
actual disc masses and radii). Back iron is stator-fixed and contributes nothing to
rotor inertia. This feeds `accel_cont = τ_cont / (J_rotor + J_load)`.

## Back iron (`iron.py`) — sanity-grade, and proud of it

An optional flat iron plate behind each stator is modeled by the **method of
images**: for a µ→∞ plane, every current element acquires a mirrored image with the
same current; two plates create an infinite reflection series, truncated after a few
bounces (each double-reflection recedes a full plate spacing, contributions die off
~1/d³). This captures the field amplification trend and the per-plate magnetic pull
(Maxwell stress integral, reported so you can size the mechanics).

Not captured: saturation (a µ→∞ plate never saturates; your 1 mm mild-steel one
will), eddy and hysteresis drag in the plate, and the negative axial stiffness of the
attraction. Treat back-iron results as a *sanity flag* — "iron would buy roughly this
much" — not as a design point to order parts against.

## The ±30% claim, itemized

The field solver is <1%; the error budget is model scope, roughly in descending
order:

1. **The as-built air gap.** Field falls steeply with axial distance (the more pole
   pairs, the steeper). ±0.2 mm of print/shim/bearing slack moves torque by tens of
   percent. This is the usual culprit when measured Kt disappoints.
2. **Magnet reality.** Br tolerance (±5% is typical for commodity NdFeB), actual
   magnetization uniformity, and the idealized sharp pole transitions vs real
   fringing between poles.
3. **Copper reality.** Etch undercut and plating variation change trace cross-section
   (worse at 2 oz), and the model ignores via/interconnect/termination resistance.
4. **Thermal hand-waving.** `h_conv` and the phase-loss lumping
   (`loss_phase_factor`) set I_cont, so continuous torque inherits their uncertainty
   even when Kt is right.
5. **Inductance ±20%**, which propagates linearly into the ripple gate.

Relative comparisons between designs evaluated by the same model are far better than
±30% — the errors are largely common-mode. That's why the tool is comfortable ranking
candidates but keeps telling you to measure before building ten.

## Validation notes

The test suite (`python -m pytest -q`, all green) pins the physics down where
closed forms or invariants exist:

- Biot–Savart vs the analytic circular-loop field, on- and off-plane, <1%
  (`test_field.py`).
- Torque linearity in current; Kt scaling with `n_stators`; Kt monotone in magnet
  grade (`test_torque.py`).
- The airgap **shear integral independently reproduces Kt** — two different
  integration routes to the same torque (`test_torque.py::test_shear_integral_matches_kt`).
- Torque comes from B_z only (`test_torque.py::test_torque_comes_from_axial_field`).
- Winding factors: 12N14P ≈ 0.94 and 36N42P ≈ 0.95 measured on generated geometry
  (`test_coils.py`); the mirrored-layer invariant (this page, war story above).
- Dual-rotor sandwich: second magnet plane doubles Bz and Kt, and exactly doubles
  rotor inertia (`test_dual_rotor.py`).
- The KiCad footprint builder re-parses its own output and refuses to write on any
  clearance/stitch/bridge failure (`test_kicad_footprint.py`).

What has *not* been done for this repo: a systematic bench calibration campaign
against built motors. The ±30% band is an engineering judgment from the itemized
sources above, not a measured statistic — one more reason to treat your first build
as the calibration article.

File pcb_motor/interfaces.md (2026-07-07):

# pcb_motor module interfaces (frozen contracts)

All quantities are **SI** (m, A, T, kg, rad). Only `field.py` converts to the
Biot-Savart kernel's internal cm/gauss units. Contracts live in `design.py`.

## Data types (`design.py`)
- `CurrentSource(vertices(N,3) m, currents(N,) A)` — universal field source.
  `currents[i]` flows in segment `i -> i+1`. `CurrentSource.concat([...])` joins
  loops with a zero-current break between them.
- `CoilGeometry` — per-segment arrays `midpoints_m(S,3)`, `dvec_m(S,3)`,
  `phase(S,)∈{0,1,2}`, `direction(S,)∈{+1,-1}`, `is_radial(S,)bool`; summaries
  `length_per_phase_m`, `conductor_area_m2`, `n_turns`, `n_layers`; `polylines`
  (list of `(K,3)` arrays, plotting only); `.end_turn_fraction` property.
- `RotorConfig` — fixed magnet rotor/stack. `.stator_z_m()` = axial gap from
  magnet mid-plane (z=0) to near stator copper plane.
- `MotorDesign` — full design point (swept knobs + fixed context). `.rotor()`
  returns the `RotorConfig`.

## Module APIs

### `field.py`
```python
def b_field_at_points(source: CurrentSource, points_m: np.ndarray,
                      resolution_m: float = 0.5e-3) -> np.ndarray:
    """B in TESLA at each point. points_m: (P,3) m. returns (P,3) T.
    Vectorised Biot-Savart: subdivide segments to resolution_m, sum
    I dl x r / |r|^3 over all segments for each point."""
```

### `magnets.py`
```python
def magnet_segments(rotor: RotorConfig, theta_rad: float = 0.0,
                    n_arc: int = 24, n_stack: int = 1) -> CurrentSource:
    """Rotor magnets as Amperian current loops. 2*pole_pairs loops at the
    magnet mid-plane (z=0), alternating current sign per pole. Loop current
    I_eq = (Br/mu0) * magnet_thickness_m (split across n_stack sub-loops).
    theta_rad rotates the whole ring. Br from pcb_motor.constants.NDFEB_BR."""
```

### `coils.py`
```python
def build_coil(design: MotorDesign) -> CoilGeometry:
    """Generate the stator winding for design.winding_topology
    ('concentrated' default; 'radial_spoke', 'spiral' alternatives). Places n
    turns that fit in (r_outer-r_inner)/(trace_width+trace_space), across
    copper_layers at z given by rotor().stator_z_m() (+ board pitch per layer),
    assigned to n_phases phases. Computes length_per_phase_m,
    conductor_area_m2 = trace_width * copper_thickness(copper_weight_oz)."""

def phase_resistance(design: MotorDesign, geo: CoilGeometry,
                     temp_c: float | None = None) -> float:
    """R_phase [ohm] = rho_cu(temp) * length_per_phase_m / conductor_area_m2,
    divided by parallel_paths**2. temp_c=None -> 20C."""
```
Uses `pcb_motor.constants.COPPER_THICKNESS`, `RHO_CU_20`, `ALPHA_CU`.

### `thermal.py`
```python
def continuous_current(design: MotorDesign, r_phase_20c: float) -> dict:
    """Lumped steady-state convection balance: returns
    {i_cont_a, r_phase_hot, p_dissipation_w, a_surface_m2, ...}. Cooled annulus
    uses cooled_faces * pi*(r_outer^2 - r_inner^2)."""
```

### `inertia.py`
```python
def rotor_inertia(rotor: RotorConfig) -> float:
    """J_rotor [kg m^2] about the axis: magnet ring + PLA carrier (back iron is
    stator-fixed, so it contributes zero rotor inertia)."""

def total_inertia(rotor: RotorConfig, load_inertia_kgm2: float) -> float:
    """rotor_inertia(rotor) + load_inertia_kgm2."""
```

### `torque.py` — depends on field/magnets/coils
```python
def kt_and_torque(design: MotorDesign, geo: CoilGeometry | None = None) -> dict:
    """B_magnet at coil midpoints via field.b_field_at_points; per segment
    dF = I*(dvec x B); tau_z = sum (r x dF)_z. Sweep commutation_steps rotor
    angles, pick the max-|tau| commutation, return {kt_nm_per_a, b_gap_mean_t,
    b_gap_peak_t, ...} where Kt = tau / I_unit. Sign: report magnitude."""
```

### `viz.py` — depends on CoilGeometry + field
```python
def plot_coil_layout(geo: CoilGeometry) -> matplotlib.figure.Figure
def plot_motor_config(rotor: RotorConfig) -> matplotlib.figure.Figure
def plot_b_field(design: MotorDesign) -> matplotlib.figure.Figure  # B_z contour
```

## Integration (`sweep.py`, `cli.py`)
`MotorDesign(bn.ParametrizedSweep)` mirrors design fields; `__call__` builds
geometry -> Kt -> I_cont -> tau_cont -> J -> a_cont = tau_cont/J_total, assigns
the result vars + three viz images.

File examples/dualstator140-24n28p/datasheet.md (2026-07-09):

# Motor design datasheet — dualstator140-24n28p

| Parameter | Value |
| --- | --- |
| Winding | concentrated, 24N28P, 3-phase, 1 parallel path(s) |
| Magnets | N52, round3, 14 pole-pairs, 3.0 mm, D12 discs @ r=61 mm, D9 discs @ r=49.5 mm, D8 discs @ r=40 mm |
| Stators | 2 x 2-layer, 0.80 mm FR4, 1 oz Cu |
| Active annulus | 30.0 - 67.0 mm |
| Trace / space | 0.600-1.497 (tapered) / 0.127 mm |
| Air gap (per side) | 1.00 mm |
| Kt (torque constant) | 128.9 mNm/A |
| Phase resistance @20C | 6.042 ohm |
| Mean / peak airgap |Bz| | 0.1326 / 0.33 T |
| Turns / phase / layer-set | 80 |
| Winding factor kw1 | 0.937 |
| Continuous current | 1.461 A |
| Continuous torque | 188.3 mNm |
| Drive voltage (cont) | 11.58 V |
| Phase inductance (air-core) | 34.78 uH |
| PWM ripple (bare winding) | 7.189 A pp worst-case @ 24 V bus, 24 kHz PWM (budget 30% of I_cont) |
| PWM ripple gate | FAIL (7.189 A pp > 0.4382 A budget, 16x -- needs ~535.7 uH/phase external L) |
| Ext. choke for ripple budget | 535.7 uH |
| Current density | 69.56 A/mm^2 |
| Airgap shear | 0.3443 kPa |
| Rotor / total inertia | 0.000475 / 0.000475 kg*m^2 |
| Continuous acceleration | 396.6 rad/s^2 |
| Copper mass | 12.16 g |

## Warnings

- PWM ripple 7.19 A pp exceeds the 0.44 A budget (16x) at 24 V bus / 24 kHz / 30% of I_cont: not drivable without ~536 uH/phase external inductance -- see design guide Stage 5.

---
*pcb-motor analytical Biot-Savart model, roughly +/-30% on absolute torque. Calibrate against FEMM or a bench coil before committing to a build.*

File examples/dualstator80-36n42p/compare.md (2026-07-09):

| Parameter | dualstator80-36n42p | dualstator80-36n42p-maxL |
| --- | --- | --- |
| Winding | concentrated, 36N42P, 3-phase, 1 parallel path(s) | concentrated, 36N42P, 3-phase, 1 parallel path(s) |
| Magnets | N52, round, 21 pole-pairs, 3.0 mm, 85% coverage | N52, round, 21 pole-pairs, 3.0 mm, 85% coverage |
| Stators | 2 x 2-layer, 0.80 mm FR4, 1 oz Cu | 2 x 2-layer, 0.80 mm FR4, 1 oz Cu |
| Active annulus | 25.0 - 38.0 mm | 25.0 - 38.0 mm |
| Trace / space | 0.500-0.826 (tapered) / 0.127 mm | 0.127-0.259 (tapered) / 0.127 mm |
| Air gap (per side) | 1.00 mm | 1.00 mm |
| Kt (torque constant) | 20.75 mNm/A | 48.97 mNm/A |
| Phase resistance @20C | 3.009 ohm | 27.04 ohm |
| Mean / peak airgap |Bz| | 0.09261 / 0.3097 T | 0.09611 / 0.311 T |
| Turns / phase | 72 | 192 |
| Winding factor kw1 | 0.943 | 0.943 |
| Continuous current | 0.9887 A | 0.3298 A |
| Continuous torque | 20.52 mNm | 16.15 mNm |
| Drive voltage (cont) | 3.904 V | 11.7 V |
| Phase inductance (air-core) | 6.687 uH | 45.52 uH |
| Ext. choke for ripple budget | 204 uH @ 9.347 A pp bare | 586.1 uH @ 1.373 A pp bare |
| Current density | 56.5 A/mm^2 | 74.2 A/mm^2 |
| Airgap shear | 0.2532 kPa | 0.1993 kPa |
| Rotor / total inertia | 3.86e-05 / 3.86e-05 kg*m^2 | 3.86e-05 / 3.86e-05 kg*m^2 |
| Continuous acceleration | 531.9 rad/s^2 | 418.7 rad/s^2 |
| Copper mass | 2.519 g | 1.889 g |

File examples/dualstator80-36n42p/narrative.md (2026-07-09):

# dualstator80-36n42p — an 80 mm no-choke attempt, honestly lost

## hero
An 80 mm pancake designed to a hard brief: maximize continuous torque on an
ODrive **without external inductors**, built only from off-the-shelf round disc
magnets and ordinary 2-layer 1 oz JLC boards. The tool did its best — 42 poles,
tapered copper, every millimetre of annulus tracked under the magnets — and then
said no to the part of the brief that physics doesn't sign off on.

## brief
Fixed by the customer: 80 mm outer diameter hard limit, ODrive drive, no chokes
if possible, maximize continuous torque. 21 pole pairs (the verified 36N42P
combo), two stators in series — one PCB each side of a single rotor disk — 2
copper layers per board, 0.8 mm FR4, 1 oz copper (JLC 5/5 mil), 1.0 mm air gap
per side, no iron anywhere. Magnet stock: real round discs only, Ø3/Ø4/Ø5/Ø6 mm,
N52.

## architecture
42 poles have to fit around a ring inside a 40 mm radius. The packing that won:
**42× Ø5×3 mm N52 discs at r = 35 mm** plus **42× Ø4×3 mm at r = 29 mm**, one
disc pair per pole, polarity alternating pole to pole. At r = 35 mm the pole
pitch is 5.24 mm, so adjacent Ø5 discs sit ~0.24 mm apart — the model is
perfectly happy with that; your 3D printer is not. Print the carrier with
open-walled pockets (adjacent discs repel, and that repulsion holds each disc
against its pocket rim). The copper annulus tracks the disc rings at
r = 25–38 mm — copper inside r = 25 mm was doing nothing but adding resistance,
so it's gone.

## hunt
This is where the no-choke hope went to die, with numbers. Inductance grows
roughly with turns squared while torque-per-ohm falls, so trace width was swept
both ways. Even maxing out turns at the fab's minimum 0.127 mm trace — a 7×
inductance gain paid for with a quarter of the continuous torque — leaves the
winding an order of magnitude short of choke-free. The committed design takes
the torque: tapered 0.50 mm traces at the 0.127 mm spacing limit.

## drive
The verdict, at the most favourable ODrive operating point (12 V bus, 48 kHz
PWM — an ODrive Pro/S1; a stock v3.6 at 24 kHz doubles the ripple): **the
no-choke brief is infeasible, by 32×.** Not marginal, not fixable with a knob:
9.35 A pp of PWM ripple on a motor rated for 0.99 A continuous. The honest
answer is three chokes in series with the phase leads — Bourns SRR1260-class
shielded drum cores.

## verdict
What the brief asked for wasn't buildable; what got built is still a good
motor: **Kt 20.75 mNm/A, 20.5 mNm continuous (±30%) at 0.99 A and 3.0 Ω**, from
two ordinary PCBs, 84 hobby-store magnets and a printed carrier. Order two
boards, wire the stators in **series** (never parallel — Stage 5 of the design
guide says why), and budget ~204 µH per phase before asking the ODrive to spin
it. Every number on this page is the analytical model talking: measure the
as-built air gap and bench-check Kt before spending real money.

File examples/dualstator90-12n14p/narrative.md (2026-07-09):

## The board this repo was built to reproduce

dualstator90-12n14p (shipped under the working name *gimbal90*) is not a
synthetic demo — it is a real, shipped 90 mm gimbal-motor stator that was
designed, hand-tuned and ordered as Gerbers before this repo existed. It's a
12-coil / 14-pole (12N14P) dual-stator machine: two of these boards sandwich one
magnet rotor, wired in series, with a mild-steel back-iron plate behind each.

What makes it the reference example is the **fully-routed artwork**: every
coil-to-coil link, the WYE star and the phase leads are baked into the
footprint as net-bearing copper — the board arrives from the fab needing no
routing at all. The tabs variant adds M3 half-hole mounts, a connector tab,
and all-PTH terminals (3.0 mm pads, 0.85 mm drills) with the terminal cluster
rotated +14° to fit a hard 100x100 mm panel.

This page was generated by `pcb-motor showcase` from the same `motor.json`
that produced the shipped boards; the regenerated copper is regression-pinned
to the shipped `.kicad_mod` files (geometric difference: zero).

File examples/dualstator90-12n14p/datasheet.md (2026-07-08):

# Motor design datasheet — concentrated 12N14P N42

| Parameter | Value |
| --- | --- |
| Winding | concentrated, 12N14P, 3-phase, 1 parallel path(s) |
| Magnets | N42, round, 7 pole-pairs, 3.0 mm, D15 discs @ r=37.2 mm, D10 discs @ r=24.4 mm |
| Stators | 2 x 2-layer, 0.80 mm FR4, 1 oz Cu |
| Active annulus | 19.0 - 44.5 mm |
| Trace / space | 0.900-2.282 (tapered) / 0.130 mm |
| Air gap (per side) | 1.00 mm |
| Kt (torque constant) | 58.22 mNm/A |
| Phase resistance @20C | 1.198 ohm |
| Mean / peak airgap |Bz| | 0.3321 / 0.5917 T |
| Turns / phase / layer-set | 32 |
| Winding factor kw1 | 0.936 |
| Continuous current | 2.203 A |
| Continuous torque | 128.3 mNm |
| Drive voltage (cont) | 3.463 V |
| Phase inductance (air-core) | 19.4 uH |
| PWM ripple (bare winding) | 2.761 A pp worst-case @ 12 V bus, 56 kHz PWM (budget 150% of I_cont) |
| PWM ripple gate | PASS (2.761 A pp <= 3.305 A budget) |
| Ext. choke for ripple budget | 0 uH |
| Current density | 69.95 A/mm^2 |
| Airgap shear | 0.7943 kPa |
| Rotor / total inertia | 0.000105 / 0.000419 kg*m^2 |
| Continuous acceleration | 306 rad/s^2 |
| Copper mass | 5.549 g |

---
*pcb-motor analytical Biot-Savart model, roughly +/-30% on absolute torque. Calibrate against FEMM or a bench coil before committing to a build.*

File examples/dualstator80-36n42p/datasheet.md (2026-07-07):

# Motor design datasheet — concentrated 36N42P N52

| Parameter | Value |
| --- | --- |
| Winding | concentrated, 36N42P, 3-phase, 1 parallel path(s) |
| Magnets | N52, round, 21 pole-pairs, 3.0 mm, D5 discs @ r=35 mm, D4 discs @ r=29 mm |
| Stators | 2 x 2-layer, 0.80 mm FR4, 1 oz Cu |
| Active annulus | 25.0 - 38.0 mm |
| Trace / space | 0.500-0.826 (tapered) / 0.127 mm |
| Air gap (per side) | 1.00 mm |
| Kt (torque constant) | 20.75 mNm/A |
| Phase resistance @20C | 3.009 ohm |
| Mean / peak airgap |Bz| | 0.09261 / 0.3097 T |
| Turns / phase / layer-set | 72 |
| Winding factor kw1 | 0.943 |
| Continuous current | 0.9887 A |
| Continuous torque | 20.52 mNm |
| Drive voltage (cont) | 3.904 V |
| Phase inductance (air-core) | 6.687 uH |
| PWM ripple (bare winding) | 9.347 A pp worst-case @ 12 V bus, 48 kHz PWM (budget 30% of I_cont) |
| PWM ripple gate | FAIL (9.347 A pp > 0.2966 A budget, 32x -- needs ~204 uH/phase external L) |
| Ext. choke for ripple budget | 204 uH |
| Current density | 56.5 A/mm^2 |
| Airgap shear | 0.2532 kPa |
| Rotor / total inertia | 3.86e-05 / 3.86e-05 kg*m^2 |
| Continuous acceleration | 531.9 rad/s^2 |
| Copper mass | 2.519 g |

## Warnings

- PWM ripple 9.35 A pp exceeds the 0.30 A budget (32x) at 12 V bus / 48 kHz / 30% of I_cont: not drivable without ~204 uH/phase external inductance -- see design guide Stage 5.

---
*pcb-motor analytical Biot-Savart model, roughly +/-30% on absolute torque. Calibrate against FEMM or a bench coil before committing to a build.*

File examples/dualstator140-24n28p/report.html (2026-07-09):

coreless axial-flux PCB motor

# dualstator140-24n28p

A coreless axial-flux motor whose stator is a circuit board: 24 copper spiral coils on 2 2-layer PCBs, a 28-pole N52 rotor, and nothing else in the magnetic circuit. The model says 188 mNm continuous (±30%) at 1.46 A -- and driving it choke-free fails the ripple gate by 16x -- budget ~536 uH of external inductance per phase.

188mNm

continuous torque (±30%)

129mNm/A

Kt

1.46A

continuous current

138mm

board OD

DRIVE GATE: FAIL

Live: the 28-pole rotor turning over the real coil artwork. Colour wash = the Biot–Savart airgap field Bz rotating with the magnets; coils light up with their commutated phase current; the bar tracks instantaneous torque.

stage 1

## The brief

What this machine was asked to be, from the session's requirements.yaml. The design and its requirements travel together, so the verdicts below are judged against these numbers, not vibes.

No requirements file in this session — the page judges the design against its own drive settings.

the machine

## Architecture

A 24-slot / 28-pole fractional-slot concentrated winding: each tooth is one continuous spiral coil, phased and signed by the star-of-slots layout, giving a fundamental winding factor kw1 = 0.937. Two stator boards sandwich a single rotor disk and are wired in series, so their torques add at the same current. There is no iron: no cogging, no saturation, and little inductance -- that constraint surfaces in the drive section.

Star-of-slots: 24 tooth coils dealt to three phases (A/B/C, ± winding sense), 28 rotor poles. Fundamental winding factor kw1 = 0.937.

explode

The axial sandwich, to scale from the design dimensions. Drag the slider (or just scroll past) to pull it apart. Back iron: none — fully coreless; the only solids are FR4, copper and the magnet rotor.

the stator

## The board itself

The actual copper. Scroll to zoom, drag to pan, toggle layers. The back layer mirrors the front about each coil's centre-line so the two layers carry current the same way around the tooth -- series connection through a via stitch, torques adding rather than cancelling.

Board artwork parsed from the production .kicad_mod footprint. Scroll/pinch to zoom, drag to pan, double-click to reset.

the trade-off

## The design hunt

The knob that matters most on a PCB winding is trace width: narrow traces pack more turns (more Kt, more inductance, much more resistance); wide traces run cooler but leave inductance behind. The sweep below is the engine re-evaluating the full design at each width -- same rotor, same annulus, same rules.

Each point is a full engine re-evaluation of the design at that trace width. The marked width is the one this design committed to.

the model

## Physics, from the real geometry

Everything here is computed from the actual geometry: vectorised Biot-Savart on the Amperian current-loop magnets gives the airgap field; the Lorentz force on every discretised copper segment, under proper 3-phase commutation, gives torque. The field map is the torque-coupling component B_z at the front copper plane.

Airgap Bz at the front copper plane (z = 2.5 mm), computed by Biot–Savart on the Amperian magnet loops. Peak |Bz| = 0.351 T. Hover for values.

Bz around the ring at the mean coil radius — the wave the copper rides on.

Torque through one electrical period at 1.46 A: commutated (flat — coreless, nothing to cog against; ripple 0.122%) and the frozen-current torque-angle characteristic it rides on.

how hard can you push it

## Thermal & continuous rating

Continuous rating is set by I²R self-heating: a lumped convection balance holds the board at the temperature limit and asks what phase current gets there. Good for 'is this thermally plausible', not for hot-spot prediction.

1.46A

continuous phase current

25.4W

copper loss at the limit

100°C

board temperature limit

69.6A/mm²

current density (neck)

11.6V

drive voltage at I_cont

7.93Ω

phase R, hot

the honest part

## Can you actually drive it?

The part most PCB-motor write-ups skip: an air-core winding has tiny inductance, so a stock FOC drive's PWM turns into large ripple current. The gate compares worst-case ripple v_bus / (4·L·f_pwm) against a budget of 30% of the continuous current.

FAIL

FAIL — worst-case PWM ripple 7.19 A pp is 16× the 0.438 A budget at 24 V bus / 24 kHz. Not drivable bare: budget ~536 µH of external inductance per phase.

34.8 µHphase inductance (air-core)

7.19 A ppworst-case PWM ripple

0.438 Aripple budget (30% of I_cont)

536 µH external L needed / phase

Choke shopping spec: ≥ 536 µH per phase → buy 680–1000 µH shielded drum-core power inductors, I_sat ≥ 2.2 A, DCR ≤ 0.6 Ω — three of them, one in series with each phase lead.

shopping list

## Fab & BOM

What you'd actually order. Boards from any fab that does 1 oz copper at these widths; magnets are off-the-shelf stock; glue, a printed carrier, and a bearing complete it.

### Boards

2× | 2-layer FR4 0.8 mm, 1 oz copper, ~Ø138 mm
| min trace/space used: 0.600 / 0.127 mm (JLC 1 oz class rules)

### Magnets & the rest

28× | Ø12 × 3 mm N52 disc magnets, axially magnetised (ring radius 61 mm)
28× | Ø9 × 3 mm N52 disc magnets, axially magnetised (ring radius 49.5 mm)
28× | Ø8 × 3 mm N52 disc magnets, axially magnetised (ring radius 40 mm)
3× | 680–1000 µH shielded power inductor, I_sat ≥ 2.2 A, DCR ≤ 0.6 Ω (series, one per phase)
| 3D-printed rotor carrier + hub (size the pockets for the disc repulsion)
| bearing + shaft to hold the air gap (1 mm per side -- the model's most sensitive parameter)

every number

## Full design parameters

The complete grouped parameter set — inputs the design chose and outputs the engine computed. This is the same data the datasheet carries.

### Architecture

Winding | concentrated, 24N28P
Phases | 3 (WYE), 1 parallel path(s)
Stators | 2 × 2-layer, in series
Winding factor kw1 | 0.937
Turns / phase / layer-set | 80

### Rotor & magnets

Magnets | N52, round3, 28 poles (14 pp)
Disc rings | Ø12 discs @ r=61 mm, Ø9 discs @ r=49.5 mm, Ø8 discs @ r=40 mm
Magnet thickness | 3 mm
Carrier thickness | 1.5 mm
Rotor sides | 1

### Board & copper

Active annulus | 30.0 – 67.0 mm
Trace width | 0.600–1.497 (tapered) mm
Trace spacing | 0.127 mm
Copper weight | 1 oz
Board thickness | 0.8 mm FR4
Air gap (per side) | 1.00 mm
Back iron | none (coreless)

### Electromagnetics (computed)

Kt (torque constant) | 128.9 mNm/A
Mean / peak airgap |Bz| | 0.1326 / 0.33 T
Phase resistance @20 °C | 6.042 Ω
Phase inductance (air-core) | 34.78 µH
Torque ripple (commutated) | 0.00042 %
Winding utilisation | 0.575

### Thermal & continuous rating (computed)

Continuous current | 1.461 A
Continuous torque | 188.3 mNm ±30%
Copper loss at limit | 25.37 W
Temp limit / ambient | 100 / 25 °C
Convection h | 15 W/m²K
Current density (neck) | 69.56 A/mm²
Drive voltage @ I_cont | 11.58 V

### Drive & parasitics

Reference drive | 24 V bus, 24 kHz PWM
Ripple budget | 30% of I_cont = 0.438 A
PWM ripple (bare winding) | 7.19 A pp
Ripple gate | FAIL (16×)
External L for budget | 536 µH/phase
Eddy loss @ ref speed | 0.0151 W

### Mechanical

Rotor inertia | 0.000475 kg·m²
Total inertia | 0.000475 kg·m²
Continuous acceleration | 396.6 rad/s²
Copper mass | 12.16 g
Airgap shear | 0.3443 kPa
Axial stack height | 6.6 mm

### Model warnings

- PWM ripple 7.19 A pp exceeds the 0.44 A budget (16x) at 24 V bus / 24 kHz / 30% of I_cont: not drivable without ~536 uH/phase external inductance -- see design guide Stage 5.

the fine print

## Verdict

On the model's numbers, dualstator140-24n28p makes 188 mNm continuously (±30%) from 12.2 g of copper -- and driving it choke-free fails the ripple gate by 16x -- budget ~536 uH of external inductance per phase.

Model honesty: this is an analytical, feasibility-grade model — treat absolute torque as ±30%. The field solver is validated to <1% against closed-form solutions; the error budget is dominated by magnet Br tolerance and fringing, your actual assembled air gap (the single most sensitive parameter), and copper etching variation. Relative comparisons between designs are much better than ±30%. Calibrate against FEMM or a bench coil before committing money to a build.

Generated by pcb-motor (https://github.com/paristhomas/pcb_motor). This page is self-contained: every number, polygon and field sample was computed by the engine and embedded at build time.

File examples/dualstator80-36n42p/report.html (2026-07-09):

coreless axial-flux PCB motor

# dualstator80-36n42p

A coreless axial-flux motor whose stator is a circuit board: 36 copper spiral coils on 2 2-layer PCBs, a 42-pole N52 rotor, and nothing else in the magnetic circuit. The model says 20.5 mNm continuous (±30%) at 0.989 A -- and driving it choke-free fails the ripple gate by 32x -- budget ~204 uH of external inductance per phase.

20.5mNm

continuous torque (±30%)

20.8mNm/A

Kt

0.989A

continuous current

80mm

board OD

DRIVE GATE: FAIL

Live: the 42-pole rotor turning over the real coil artwork. Colour wash = the Biot–Savart airgap field Bz rotating with the magnets; coils light up with their commutated phase current; the bar tracks instantaneous torque.

stage 1

## The brief

What this machine was asked to be, from the session's requirements.yaml. The design and its requirements travel together, so the verdicts below are judged against these numbers, not vibes.

application

flat pancake motor, ODrive-driven, NO external inductors/chokes if possible

objective

maximize continuous torque at the thermal limit

torque cont mNm

maximize

speed rpm

unspecified (assume low; pancake/direct-drive class)

bus voltage V

12-56 (ODrive range) — designer's choice, pick what makes no-choke closest

drive

ODrive FOC; f_pwm 24 kHz stock (ODrive S1/Pro can run up to 48 kHz)

drive ripple budget

repo default 30% of I_cont (drive_ripple_frac=0.3)

envelope

{'outer_diameter_mm': 80, 'bore_mm': 'unspecified', 'axial_mm': 'unspecified'}

Duty

continuous

hard constraints

{'pole_pairs': 21, 'n_stators': 2, 'copper_layers_per_pcb': 2, 'board_thickness_mm': 0.8, 'copper_weight_oz': 1.0, 'back_iron': 'none anywhere', 'air_gap_mm': '1.0 per side (mechanical)'}

stock

{'magnets': 'off-the-shelf round disc magnets only (magnet_topology=round); real sizes Ø3/Ø4/Ø5/Ø6 mm x 1-3 mm, N35-N52 (N52 assumed purchasable)', 'fab': 'JLCPCB 2-layer standard, 1 oz (5/5 mil min)'}

open questions

['no-choke feasibility must be judged against the repo gate ripple_pp = v_bus/(4*L*f_pwm) vs drive_ripple_frac * i_cont']

the machine

## Architecture

A 36-slot / 42-pole fractional-slot concentrated winding: each tooth is one continuous spiral coil, phased and signed by the star-of-slots layout, giving a fundamental winding factor kw1 = 0.943. Two stator boards sandwich a single rotor disk and are wired in series, so their torques add at the same current. There is no iron: no cogging, no saturation, and little inductance -- that constraint surfaces in the drive section.

Star-of-slots: 36 tooth coils dealt to three phases (A/B/C, ± winding sense), 42 rotor poles. Fundamental winding factor kw1 = 0.943.

explode

The axial sandwich, to scale from the design dimensions. Drag the slider (or just scroll past) to pull it apart. Back iron: none — fully coreless; the only solids are FR4, copper and the magnet rotor.

the stator

## The board itself

The actual copper. Scroll to zoom, drag to pan, toggle layers. The back layer mirrors the front about each coil's centre-line so the two layers carry current the same way around the tooth -- series connection through a via stitch, torques adding rather than cancelling.

Board artwork parsed from the production .kicad_mod footprint. Scroll/pinch to zoom, drag to pan, double-click to reset.

the trade-off

## The design hunt

The knob that matters most on a PCB winding is trace width: narrow traces pack more turns (more Kt, more inductance, much more resistance); wide traces run cooler but leave inductance behind. The sweep below is the engine re-evaluating the full design at each width -- same rotor, same annulus, same rules.

Each point is a full engine re-evaluation of the design at that trace width. The marked width is the one this design committed to.

the model

## Physics, from the real geometry

Everything here is computed from the actual geometry: vectorised Biot-Savart on the Amperian current-loop magnets gives the airgap field; the Lorentz force on every discretised copper segment, under proper 3-phase commutation, gives torque. The field map is the torque-coupling component B_z at the front copper plane.

Airgap Bz at the front copper plane (z = 2.5 mm), computed by Biot–Savart on the Amperian magnet loops. Peak |Bz| = 0.317 T. Hover for values.

Bz around the ring at the mean coil radius — the wave the copper rides on.

Torque through one electrical period at 0.989 A: commutated (flat — coreless, nothing to cog against; ripple 0.00391%) and the frozen-current torque-angle characteristic it rides on.

how hard can you push it

## Thermal & continuous rating

Continuous rating is set by I²R self-heating: a lumped convection balance holds the board at the temperature limit and asks what phase current gets there. Good for 'is this thermally plausible', not for hot-spot prediction.

0.989A

continuous phase current

5.79W

copper loss at the limit

100°C

board temperature limit

56.5A/mm²

current density (neck)

3.9V

drive voltage at I_cont

3.95Ω

phase R, hot

the honest part

## Can you actually drive it?

The part most PCB-motor write-ups skip: an air-core winding has tiny inductance, so a stock FOC drive's PWM turns into large ripple current. The gate compares worst-case ripple v_bus / (4·L·f_pwm) against a budget of 30% of the continuous current.

FAIL

FAIL — worst-case PWM ripple 9.35 A pp is 32× the 0.297 A budget at 12 V bus / 48 kHz. Not drivable bare: budget ~204 µH of external inductance per phase.

6.69 µHphase inductance (air-core)

9.35 A ppworst-case PWM ripple

0.297 Aripple budget (30% of I_cont)

204 µH external L needed / phase

Choke shopping spec: ≥ 204 µH per phase → buy 220–330 µH shielded drum-core power inductors, I_sat ≥ 1.5 A, DCR ≤ 0.3 Ω — three of them, one in series with each phase lead.

shopping list

## Fab & BOM

What you'd actually order. Boards from any fab that does 1 oz copper at these widths; magnets are off-the-shelf stock; glue, a printed carrier, and a bearing complete it.

### Boards

2× | 2-layer FR4 0.8 mm, 1 oz copper, ~Ø80 mm
| min trace/space used: 0.500 / 0.127 mm (JLC 1 oz class rules)

### Magnets & the rest

42× | Ø5 × 3 mm N52 disc magnets, axially magnetised (ring radius 35 mm)
42× | Ø4 × 3 mm N52 disc magnets, axially magnetised (ring radius 29 mm)
3× | 220–330 µH shielded power inductor, I_sat ≥ 1.5 A, DCR ≤ 0.3 Ω (series, one per phase)
| 3D-printed rotor carrier + hub (size the pockets for the disc repulsion)
| bearing + shaft to hold the air gap (1 mm per side -- the model's most sensitive parameter)

every number

## Full design parameters

The complete grouped parameter set — inputs the design chose and outputs the engine computed. This is the same data the datasheet carries.

### Architecture

Winding | concentrated, 36N42P
Phases | 3 (WYE), 1 parallel path(s)
Stators | 2 × 2-layer, in series
Winding factor kw1 | 0.943
Turns / phase / layer-set | 72

### Rotor & magnets

Magnets | N52, round, 42 poles (21 pp)
Disc rings | Ø5 discs @ r=35 mm, Ø4 discs @ r=29 mm
Magnet thickness | 3 mm
Carrier thickness | 1.5 mm
Rotor sides | 1

### Board & copper

Active annulus | 25.0 – 38.0 mm
Trace width | 0.500–0.826 (tapered) mm
Trace spacing | 0.127 mm
Copper weight | 1 oz
Board thickness | 0.8 mm FR4
Air gap (per side) | 1.00 mm
Back iron | none (coreless)

### Electromagnetics (computed)

Kt (torque constant) | 20.75 mNm/A
Mean / peak airgap |Bz| | 0.09261 / 0.3097 T
Phase resistance @20 °C | 3.009 Ω
Phase inductance (air-core) | 6.687 µH
Torque ripple (commutated) | 3.6e-05 %
Winding utilisation | 0.621

### Thermal & continuous rating (computed)

Continuous current | 0.9887 A
Continuous torque | 20.52 mNm ±30%
Copper loss at limit | 5.789 W
Temp limit / ambient | 100 / 25 °C
Convection h | 15 W/m²K
Current density (neck) | 56.5 A/mm²
Drive voltage @ I_cont | 3.904 V

### Drive & parasitics

Reference drive | 12 V bus, 48 kHz PWM
Ripple budget | 30% of I_cont = 0.297 A
PWM ripple (bare winding) | 9.35 A pp
Ripple gate | FAIL (32×)
External L for budget | 204 µH/phase
Eddy loss @ ref speed | 0.00122 W

### Mechanical

Rotor inertia | 3.86e-05 kg·m²
Total inertia | 3.86e-05 kg·m²
Continuous acceleration | 531.9 rad/s²
Copper mass | 2.519 g
Airgap shear | 0.2532 kPa
Axial stack height | 6.6 mm

### Model warnings

- PWM ripple 9.35 A pp exceeds the 0.30 A budget (32x) at 12 V bus / 48 kHz / 30% of I_cont: not drivable without ~204 uH/phase external inductance -- see design guide Stage 5.

the fine print

## Verdict

On the model's numbers, dualstator80-36n42p makes 20.5 mNm continuously (±30%) from 2.52 g of copper -- and driving it choke-free fails the ripple gate by 32x -- budget ~204 uH of external inductance per phase.

Model honesty: this is an analytical, feasibility-grade model — treat absolute torque as ±30%. The field solver is validated to <1% against closed-form solutions; the error budget is dominated by magnet Br tolerance and fringing, your actual assembled air gap (the single most sensitive parameter), and copper etching variation. Relative comparisons between designs are much better than ±30%. Calibrate against FEMM or a bench coil before committing money to a build.

Generated by pcb-motor (https://github.com/paristhomas/pcb_motor) — This page is self-contained: every number, polygon and field sample was computed by the engine and embedded at build time.

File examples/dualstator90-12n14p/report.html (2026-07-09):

coreless axial-flux PCB motor

# dualstator90-12n14p

A coreless axial-flux motor whose stator is a circuit board: 12 copper spiral coils on 2 2-layer PCBs, a 14-pole N42 rotor, and nothing else in the magnetic circuit. The model says 128 mNm continuous (±30%) at 2.2 A -- and it passes its own drive-feasibility gate.

128mNm

continuous torque (±30%)

58.2mNm/A

Kt

2.2A

continuous current

93mm

board OD

DRIVE GATE: PASS

Live: the 14-pole rotor turning over the real coil artwork. Colour wash = the Biot–Savart airgap field Bz rotating with the magnets; coils light up with their commutated phase current; the bar tracks instantaneous torque.

stage 1

## The brief

What this machine was asked to be, from the session's requirements.yaml. The design and its requirements travel together, so the verdicts below are judged against these numbers, not vibes.

No requirements file in this session — the page judges the design against its own drive settings.

the machine

## Architecture

A 12-slot / 14-pole fractional-slot concentrated winding: each tooth is one continuous spiral coil, phased and signed by the star-of-slots layout, giving a fundamental winding factor kw1 = 0.936. Two stator boards sandwich a single rotor disk and are wired in series, so their torques add at the same current. There is no iron: no cogging, no saturation, and little inductance -- that constraint surfaces in the drive section.

Star-of-slots: 12 tooth coils dealt to three phases (A/B/C, ± winding sense), 14 rotor poles. Fundamental winding factor kw1 = 0.936.

explode

The axial sandwich, to scale from the design dimensions. Drag the slider (or just scroll past) to pull it apart. Back iron: yes — 2 mild-steel return plates (grey, hatched) flush behind the stators.

the stator

## The board itself

The actual copper. Scroll to zoom, drag to pan, toggle layers. The back layer mirrors the front about each coil's centre-line so the two layers carry current the same way around the tooth -- series connection through a via stitch, torques adding rather than cancelling.

Board artwork parsed from the production .kicad_mod footprint. Scroll/pinch to zoom, drag to pan, double-click to reset.

the trade-off

## The design hunt

The knob that matters most on a PCB winding is trace width: narrow traces pack more turns (more Kt, more inductance, much more resistance); wide traces run cooler but leave inductance behind. The sweep below is the engine re-evaluating the full design at each width -- same rotor, same annulus, same rules.

Each point is a full engine re-evaluation of the design at that trace width. The marked width is the one this design committed to.

the model

## Physics, from the real geometry

Everything here is computed from the actual geometry: vectorised Biot-Savart on the Amperian current-loop magnets gives the airgap field; the Lorentz force on every discretised copper segment, under proper 3-phase commutation, gives torque. The field map is the torque-coupling component B_z at the front copper plane.

Airgap Bz at the front copper plane (z = 2.5 mm), computed by Biot–Savart on the Amperian magnet loops. Peak |Bz| = 0.592 T. Hover for values.

Bz around the ring at the mean coil radius — the wave the copper rides on.

Torque through one electrical period at 2.2 A: commutated (flat — coreless, nothing to cog against; ripple 0.0751%) and the frozen-current torque-angle characteristic it rides on.

how hard can you push it

## Thermal & continuous rating

Continuous rating is set by I²R self-heating: a lumped convection balance holds the board at the temperature limit and asks what phase current gets there. Good for 'is this thermally plausible', not for hot-spot prediction.

2.2A

continuous phase current

11.4W

copper loss at the limit

100°C

board temperature limit

69.9A/mm²

current density (neck)

3.46V

drive voltage at I_cont

1.57Ω

phase R, hot

the honest part

## Can you actually drive it?

The part most PCB-motor write-ups skip: an air-core winding has tiny inductance, so a stock FOC drive's PWM turns into large ripple current. The gate compares worst-case ripple v_bus / (4·L·f_pwm) against a budget of 150% of the continuous current.

PASS

PASS — worst-case PWM ripple 2.76 A pp fits the 3.31 A budget at 12 V bus / 56 kHz. No choke needed.

19.4 µHphase inductance (air-core)

2.76 A ppworst-case PWM ripple

3.31 Aripple budget (150% of I_cont)

— external L needed / phase

shopping list

## Fab & BOM

What you'd actually order. Boards from any fab that does 1 oz copper at these widths; magnets are off-the-shelf stock; glue, a printed carrier, and a bearing complete it.

### Boards

2× | 2-layer FR4 0.8 mm, 1 oz copper, ~Ø93 mm
| min trace/space used: 0.900 / 0.130 mm (JLC 1 oz class rules)

### Magnets & the rest

14× | Ø15 × 3 mm N42 disc magnets, axially magnetised (ring radius 37.2 mm)
14× | Ø10 × 3 mm N42 disc magnets, axially magnetised (ring radius 24.4 mm)
| 3D-printed rotor carrier + hub (size the pockets for the disc repulsion)
| bearing + shaft to hold the air gap (1 mm per side -- the model's most sensitive parameter)

every number

## Full design parameters

The complete grouped parameter set — inputs the design chose and outputs the engine computed. This is the same data the datasheet carries.

### Architecture

Winding | concentrated, 12N14P
Phases | 3 (WYE), 1 parallel path(s)
Stators | 2 × 2-layer, in series
Winding factor kw1 | 0.936
Turns / phase / layer-set | 32

### Rotor & magnets

Magnets | N42, round, 14 poles (7 pp)
Disc rings | Ø15 discs @ r=37.2 mm, Ø10 discs @ r=24.4 mm
Magnet thickness | 3 mm
Carrier thickness | 1.5 mm
Rotor sides | 1

### Board & copper

Active annulus | 19.0 – 44.5 mm
Trace width | 0.900–2.282 (tapered) mm
Trace spacing | 0.130 mm
Copper weight | 1 oz
Board thickness | 0.8 mm FR4
Air gap (per side) | 1.00 mm
Back iron | yes

### Electromagnetics (computed)

Kt (torque constant) | 58.22 mNm/A
Mean / peak airgap |Bz| | 0.3321 / 0.5917 T
Phase resistance @20 °C | 1.198 Ω
Phase inductance (air-core) | 19.4 µH
Torque ripple (commutated) | 0.00095 %
Winding utilisation | 0.626

### Thermal & continuous rating (computed)

Continuous current | 2.203 A
Continuous torque | 128.3 mNm ±30%
Copper loss at limit | 11.45 W
Temp limit / ambient | 100 / 25 °C
Convection h | 15 W/m²K
Current density (neck) | 69.95 A/mm²
Drive voltage @ I_cont | 3.463 V

### Drive & parasitics

Reference drive | 12 V bus, 56 kHz PWM
Ripple budget | 150% of I_cont = 3.31 A
PWM ripple (bare winding) | 2.76 A pp
Ripple gate | PASS
External L for budget | 0 µH/phase
Eddy loss @ ref speed | 0.0256 W

### Mechanical

Rotor inertia | 0.000105 kg·m²
Total inertia | 0.000419 kg·m²
Continuous acceleration | 306 rad/s²
Copper mass | 5.549 g
Airgap shear | 0.7943 kPa
Axial stack height | 8.6 mm

the fine print

## Verdict

On the model's numbers, dualstator90-12n14p makes 128 mNm continuously (±30%) from 5.55 g of copper -- and it passes its own drive-feasibility gate.

Model honesty: this is an analytical, feasibility-grade model — treat absolute torque as ±30%. The field solver is validated to <1% against closed-form solutions; the error budget is dominated by magnet Br tolerance and fringing, your actual assembled air gap (the single most sensitive parameter), and copper etching variation. Relative comparisons between designs are much better than ±30%. Calibrate against FEMM or a bench coil before committing money to a build.

Generated by pcb-motor (https://github.com/paristhomas/pcb_motor) — This page is self-contained: every number, polygon and field sample was computed by the engine and embedded at build time.

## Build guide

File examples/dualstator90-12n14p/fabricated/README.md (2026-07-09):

# gimbal90 — the board that was fabricated

These are the **exact production files for the gimbal90 routed-tabs stator that
was physically manufactured** (the "main event"). They are checked in verbatim
as the golden reference:

- `gimbal90_routed_tabs.kicad_pcb` / `.kicad_pro` — the KiCad board sent to fab.
- `gimbal90_routed_TABS_gerbers.zip` — the Gerber set that was ordered.

**What this proves.** `pcb-motor board --session dualstator90-12n14p --gerbers` regenerates
this board from the committed routed footprint and exports its Gerbers. The
regenerated `.kicad_pcb` is **coordinate-for-coordinate identical** to this one
(same 17,665 copper/edge points, same bore, same placement), and Gerbers plotted
from it by the same `kicad-cli` are **byte-identical modulo timestamps** on every
copper / mask / silk / edge layer. See `tests/test_board_fabequiv.py`.

The ordered Gerber set omits the paste layers and the drill map (not needed for
this board); the tool's default set includes them, which is a harmless superset
— the copper, soldermask, silkscreen, edge cuts and drills are the same board.

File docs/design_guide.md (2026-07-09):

# The PCB motor design guide

This is the full walkthrough: everything between "I think I want a PCB motor" and a
zip file on its way to JLCPCB. It follows one worked example the whole way — an 80 mm
gimbal motor we'll call `pancake80` — and every command shown here was actually run
against this repo. If you'd rather delegate, open Claude Code in this repo and describe
your motor; the `.claude/skills/pcb-motor-design` skill walks these exact stages. This
document is for humans (and for checking the agent's work).

The machine we're designing: a **coreless axial-flux motor** with one rotor — a ring
of alternating-polarity magnets on a 3D-printed carrier — sandwiched between **two
stator PCBs wired in series**. That dual-stator/single-rotor sandwich is the default
and recommended configuration; both boards are identical, which is convenient, because
PCBs are cheap in multiples of five.

## Stage 0 — Install

```bash
python3 -m venv .venv
.venv/bin/pip install -e ".[dev]"
source .venv/bin/activate
```

Sanity check: `python -m pytest -q` should be green, and `pcb-motor new --session
scratch` should print a table of numbers. Everything below assumes the venv is active;
otherwise prefix commands with `.venv/bin/`.

## Stage 1 — Write down the requirements

Resist the urge to type `--set` flags. The single most common failure mode in motor
design is optimizing a number nobody needed. Establish, roughly:

- **Torque** — continuous, and peak if it differs. This is usually THE requirement.
- **Speed** — operating speed matters for eddy losses and drive voltage headroom.
- **Voltage & drive** — bus voltage, driver type (ODrive-class FOC? cheap ESC?),
  switching frequency. This decides the winding and the choke question (Stage 5).
- **Envelope** — max outer diameter, hub/bore diameter, total axial thickness.
- **Duty** — continuous or burst. Decides how hard the thermal limit bites.
- **Fixed stock** — magnet sizes/grades you can actually buy, board-house limits
  (copper weight, min trace/space). These are *inputs, not knobs*: don't let an
  optimizer pick a magnet that doesn't exist.

Write them into the session directory so they survive your enthusiasm
(`pcb-motor new` seeds a commented `requirements.yaml` skeleton with exactly these
keys if the file doesn't exist yet). For our worked
example, `designs/pancake80/requirements.yaml`:

```yaml
application: camera gimbal, direct drive
torque_cont_mNm: 50        # holding + slew against slightly unbalanced payload
speed_rpm: <300            # slow; eddy losses irrelevant
bus_voltage_V: 24
drive: ODrive-class FOC, f_pwm 48 kHz
envelope:
  outer_diameter_mm: 80    # hard limit
  bore_mm: 30              # cable pass-through
  axial_mm: 12
duty: continuous
stock:
  magnets: N52 arc segments, 3 mm thick (or round discs as fallback)
  fab: JLCPCB 2-layer; 1 oz (5/5 mil) or 2 oz (8/8 mil) copper
```

## Stage 2 — Seed a design that fits the envelope

A session is created with `pcb-motor new --session <name>`, which saves a `MotorDesign`
(defaults + your `--set` overrides) into `designs/<name>/motor.json` and immediately
evaluates it. All `--set` fields are SI (`_m`, `_hz` suffixes mean what they say);
`pcb-motor fields` prints every settable field, grouped, with its default and meaning.

The knobs, grouped. Defaults in parentheses.

**Geometry — the coil and board (the stuff you'll iterate most):**

| Field | Default | What it does |
|---|---|---|
| `r_inner_m` / `r_outer_m` | 10/30 mm | Active copper annulus. Torque scales hard with radius — use the envelope. |
| `trace_width_m` | 0.15 mm | Conductor width (at `r_inner` if tapered). Wider → lower R, fewer turns → lower Kt. |
| `trace_space_m` | 0.15 mm | Copper-to-copper gap. Set by your board house (Stage 7), not by taste. |
| `tapered_traces` | false | Wedge traces at constant angular pitch: width grows with radius, clearance held everywhere. **Turn this on for anything you'll fabricate** — it's what the production footprint emits. |
| `copper_layers` | 2 | Layers per board. Back layer is the mirror of the front (in series, torque-additive). |
| `copper_weight_oz` | 1.0 | Foil thickness. 2 oz halves R without touching Kt — but relaxes min trace/space to 0.20 mm at JLC. |
| `board_thickness_m` | 0.8 mm | FR4 thickness; part of the magnetic gap for the far layer. |
| `n_slots` | 12 | Number of concentrated coils. Pair with `pole_pairs` — see the star-of-slots section in Stage 4. |
| `winding_topology` | concentrated | `concentrated` is the fabricable one; `radial_spoke`/`spiral` exist for studies. |
| `parallel_paths` | 1 | Splits the winding into parallel groups: Kt/p, R/p² — the lever for taming drive voltage. |
| `corner_radius_m` | 0.15 mm | Fillet on sharp trace corners (drawn geometry only). |

**Magnets — the rotor:**

| Field | Default | What it does |
|---|---|---|
| `pole_pairs` | 7 | Magnetic poles = 2×this. More poles → shorter end-turns and more Kt up to a point, finer features beyond it. |
| `magnet_grade` | N42 | NdFeB grade → Br. Buy what's actually stocked. |
| `magnet_thickness_m` | 3 mm | Thicker → more field, with diminishing returns once thickness ≳ pole pitch. |
| `magnet_r_inner_m` / `magnet_r_outer_m` | 10/30 mm | Magnet annulus; roughly track the coil annulus. |
| `pole_coverage` | 0.85 | Fraction of each pole pitch covered by magnet (arc topology). |
| `magnet_topology` | arc | `arc` = continuous pole-arc ring (custom arc segments). `round` = two concentric rings of off-the-shelf round disc magnets — the buy-it-today rotor (`outer_ring_r_m`, `outer_disc_d_m`, `inner_ring_r_m`, `inner_disc_d_m`). `round3` = same, plus a middle ring (`mid_ring_r_m`, `mid_disc_d_m`) to fill the radial gap over active copper. |
| `carrier_thickness_m` | 1.5 mm | 3D-printed rotor carrier, counted in rotor inertia. |

#### Round-disc rotors (`magnet_topology="round"`)

The round rotor is built from **two concentric rings of stock disc magnets** — every
pole is one outer disc plus one inner disc, same polarity, alternating pole to pole.
Four fields describe it (defaults in parentheses):

| Field | Default | What it does |
|---|---|---|
| `outer_ring_r_m` | 37.2 mm | Centre radius of the outer disc ring. |
| `outer_disc_d_m` | 15 mm | Outer disc diameter (default fits stock Ø15). |
| `inner_ring_r_m` | 20.6 mm | Centre radius of the inner disc ring. |
| `inner_disc_d_m` | 8 mm | Inner disc diameter (default fits stock Ø8). |

Worked example — the rotor of the committed [`examples/dualstator80-36n42p`](../examples/dualstator80-36n42p/README.md)
design, 42× Ø5×3 mm N52 outer + 42× Ø4×3 mm N52 inner discs (42 poles = one disc
pair per pole), tried here against our running session:

```bash
pcb-motor point --session pancake80 \
  --set magnet_topology=round \
  --set outer_ring_r_m=35e-3 --set outer_disc_d_m=5e-3 \
  --set inner_ring_r_m=29e-3 --set inner_disc_d_m=4e-3
```

Two things to know before sweeping these:

- **`pole_coverage`, `magnet_r_inner_m`, and `magnet_r_outer_m` are arc-topology
  parameters — they have no effect in round mode.** The disc rings fully define the
  round rotor's magnet geometry (the datasheet suppresses the coverage figure for
  round rotors for the same reason). Don't waste sweep budget on them.
- Single-ring study variants exist: `round_outer` (outer ring only) and
  `round_inner` (inner ring only) — useful for asking what each ring buys.
- A **third ring** (`magnet_topology="round3"`, adding `mid_ring_r_m` / `mid_disc_d_m`)
  fills the radial band between the inner and outer rings. That band is empty of field
  but full of current-carrying copper, so a middle ring turns otherwise-idle copper into
  torque (see [`examples/dualstator140-24n28p`](../examples/dualstator140-24n28p/README.md)).
  Size the discs so they **don't shrink going outward** (outer radius has more room and
  more moment arm), and keep **≥0.8 mm of carrier between every disc** — the engine warns
  below that (both pole-to-pole and ring-to-ring), which bounds where each ring can sit.

Sanity-check the geometry after choosing radii/diameters: adjacent discs on a ring
must not overlap, and see the Stage 7 carrier-wall note before you fall in love with
a packing the printer can't build.

**Stack — how boards and rotor sandwich together:**

| Field | Default | What it does |
|---|---|---|
| `n_stators` | 2 | Stator boards, wired in **series**. The default machine is the two-boards-one-rotor sandwich. Kt and R both scale with it. |
| `air_gap_m` | 1.0 mm | Mechanical gap magnet-face → board, per side. **The single most sensitive number in the whole design** — and your mechanical tolerances own it. |
| `rotor_sides` | 1 | Alternative topology: `2` = dual-rotor sandwich (magnets both sides of ONE board; requires `n_stators=1`, no iron). Fields add at the stator, but the two magnet plates attract each other hard — see Stage 7. |
| `back_iron` | false | Flat iron plate behind each stator. Boosts field, adds attraction force; modeled sanity-grade only (see physics.md). |
| `iron_standoff_m` | 0 | Extra spacing board-back → iron plate. |

**Drive — reference electrical context (used by the Stage 5 gate):**

| Field | Default | What it does |
|---|---|---|
| `drive_v_bus` | 12 V | DC bus voltage. |
| `drive_f_pwm_hz` | 24 kHz | Driver switching frequency. |
| `drive_ripple_frac` | 0.3 | Ripple budget: allowed PWM ripple as a fraction of continuous current. |
| `ref_speed_rev_s` | 5 | Mechanical speed for the eddy-loss estimate. |

**Thermal / load:**

| Field | Default | What it does |
|---|---|---|
| `temp_limit_c` / `ambient_c` | 100/25 °C | Copper temperature limit and ambient — sets the thermal budget. |
| `h_conv` | 15 W/m²K | Convection film coefficient (still air ~10–15; a fan changes your life). |
| `cooled_faces` | 2 | How many board faces shed heat. |
| `load_inertia_kgm2` | 0 | Add your load so `accel_cont` means something. |

Seed the worked example — 80 mm OD means a copper annulus out to 38 mm (leaving rim
for the board edge), 36 slots / 21 pole pairs (see Stage 4 for why), and our drive
context:

```bash
pcb-motor new --session pancake80 \
  --set pole_pairs=21 --set n_slots=36 \
  --set r_outer_m=38e-3 --set r_inner_m=18e-3 \
  --set magnet_r_outer_m=38e-3 --set magnet_r_inner_m=16e-3 \
  --set magnet_thickness_m=2e-3 \
  --set drive_v_bus=24 --set drive_f_pwm_hz=48e3
```

```text
session saved to designs/pancake80
pcb-motor point  [concentrated, 21pp, N42, 2 stator(s)]
--------------------------------------------------------
  Continuous acceleration             510.5 rad/s^2
  Continuous torque                   23.76 mNm
  Kt (torque constant)                74.08 mNm/A
  Continuous current                 0.3207 A
  ...
  Drive voltage (cont)                16.46 V
  Phase inductance (air-core)         54.75 uH
  PWM ripple @bus/fsw                 2.283 A pp
  Ext. L for ripple budget             1244 uH
  ...
  Winding factor kw1                 0.9456
```

23.8 mNm continuous against a 50 mNm target: short by 2×. That's normal for a first
seed. On to the numbers.

## Stage 3 — Evaluate: what the numbers mean

`pcb-motor point --session <name>` re-evaluates; add `--set` to test a change without
saving it. The headline metrics, and what healthy looks like:

- **`Continuous torque` / `Kt` / `Continuous current`** — τ_cont = Kt·I_cont, where
  I_cont is the *thermal* limit (copper loss = convection at `temp_limit_c`). For an
  FR4 coreless stator the thermal limit binds long before magnetics does.
- **`Winding factor kw1`** — should be **≥ 0.9** (the supported layouts give
  0.93–0.95). If you see ~0.3, or 0.00, your slot/pole combination fell into the
  round-robin fallback and the winding is fighting itself — fix it (Stage 4), don't
  try to optimize past it.
- **`Drive voltage (cont)`** — phase voltage needed to push I_cont through R_hot. Must
  sit below your bus with real margin (you also need voltage headroom for back-EMF at
  speed and for the current controller to act). If it's over: `parallel_paths`.
- **`Current density`** — a sanity flag, not an enforced limit. PCB stators run far
  above wire-motor rules of thumb because 35–70 µm foil on FR4 is thermally
  well-coupled to the board surface; tens of A/mm² continuous is normal here (our
  examples land 45–75). Treat big jumps as a flag: with `tapered_traces` this reports
  the *narrowest* point (at `r_inner`), so a spike means a hot neck — widen
  `trace_width_m` or move `r_inner_m` out.
- **`Phase resistance` / `Phase inductance`** — machine **totals for all `n_stators`
  boards wired in series**: both scale exactly ×`n_stators`, so on the default
  two-board machine each board contributes half of the printed R and L. Compare
  against per-board bench measurements accordingly — and note the Stage 5 ripple
  gate hinges on this total L, which is precisely why parallel-wiring the boards
  (halving L) is forbidden.
- **`PWM ripple @bus/fsw` and `Ext. L for ripple budget`** — the Stage 5 gate. Ripple
  bigger than the continuous current itself means your drive would mostly be making
  heat and acoustic art.
- **`Mean airgap |Bz|`** — 0.1–0.25 T is the realistic coreless-PCB range. Raise it
  with thicker/stronger/closer magnets, or a second rotor/back iron.
- **`Airgap shear`** — torque per swept area. Coreless PCB machines live around
  0.1–1 kPa (iron machines: 10–100×that). A "how hard is the airgap working" gauge,
  useful for comparing designs.
- **`End-turn fraction`** — copper length not producing torque. 0.28 for 12 slots,
  0.11 for 36 slots — one reason more slots pays at large diameter.
- **`Winding utilisation`** — commutated torque vs the ideal sum (~0.64–0.69 typical);
  a low outlier means commutation is wasting the copper.
- **`Continuous acceleration`** — τ_cont/J with your `load_inertia_kgm2`. The default
  objective when inertia matters (reaction wheels, gimbals); meaningless if you left
  the load at 0 and care about torque only.
- **Warnings** — printed at the bottom, they're real. This model refuses to silently
  paper over the things it doesn't compute.

## Stage 4 — Iterate

### By hand (recommended first)

`--set` on `point` commits you to nothing — the change isn't saved until you re-run
`new`. It isn't *instant*, though: every `point` is a real Biot–Savart solve, ~30–60 s
of compute, so a hand-swept five-value comparison is a few-minute coffee, not a
keystroke (the `[sweep]` extra parallelizes real sweeps — see below). Our seed's
problem was torque, and its drive voltage (16.5 V of 24 V) said "the winding is
thinner than it needs to be". Trade turns for copper: 2 oz foil, respaced to JLC's
2 oz minimum (0.20 mm), tapered so the clearance holds at every radius:

```bash
pcb-motor point --session pancake80 \
  --set copper_weight_oz=2 --set trace_width_m=0.2e-3 \
  --set trace_space_m=0.2e-3 --set tapered_traces=true
```

```text
  Continuous torque                   37.93 mNm
  Kt (torque constant)                37.36 mNm/A
  Continuous current                  1.015 A
  Drive voltage (cont)                5.198 V
  ...
```

+60% torque. Still short. The remaining big levers are magnetic: N52 instead of N42,
3 mm magnets, and — the strongest and scariest lever — the air gap. Going 1.0 → 0.8 mm
per side (tight but holdable with a printed carrier and honest bearings):

```bash
pcb-motor new --session pancake80 \
  --set pole_pairs=21 --set n_slots=36 \
  --set r_outer_m=38e-3 --set r_inner_m=18e-3 \
  --set magnet_r_outer_m=38e-3 --set magnet_r_inner_m=16e-3 \
  --set magnet_thickness_m=3e-3 --set magnet_grade=N52 \
  --set air_gap_m=0.8e-3 \
  --set copper_weight_oz=2 --set trace_width_m=0.2e-3 \
  --set trace_space_m=0.2e-3 --set tapered_traces=true \
  --set drive_v_bus=24 --set drive_f_pwm_hz=48e3
```

```text
  Continuous torque                   49.26 mNm
  Kt (torque constant)                48.52 mNm/A
  Continuous current                  1.015 A
  Drive voltage (cont)                5.198 V
  Winding factor kw1                 0.9491
```

49.3 mNm against a 50 mNm target — done, to well within the model's honesty band
(±30%: measure before you celebrate). Note what we did *not* do: shrink `trace_space`
below the fab minimum, or invent a magnet. Re-running `new` saved this as the session's
design.

One artifact to expect while iterating: the winder fits an **integer number of turns**
into each tooth, so a fine `trace_width_m` (or `trace_space_m`) sweep moves in
plateaus — Kt barely moves while the turn count holds, then steps when a turn is
gained or lost, and can even wiggle non-monotonically by a percent or two at constant
turn count as the spiral re-packs. That's quantization, not noise: watch the
`Turns / phase / layer-set` line, and don't chase sub-plateau differences.

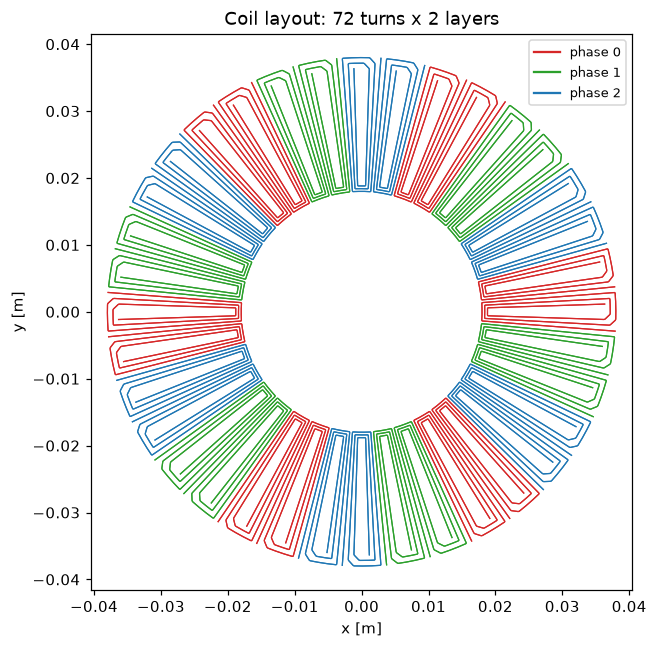
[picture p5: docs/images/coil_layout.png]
The pancake80 winding


### Picking slot and pole counts (read this before optimizing)

Concentrated windings only work when the slot/pole combination puts each phase's coils
at compatible electrical angles — the classic **star of slots** business. The layout
table in `pcb_motor/coils.py` ships verified entries for the **12N14P family**
(12 slots / 14 poles, and its 3× tiling **36N42P** — 36 slots / 42 poles), plus the
12-slot table also serves 12N10P. Measured kw1 on the generated geometry:

| Combo | kw1 | Verdict |
|---|---|---|
| 12N14P | 0.939 | the small-motor default |
| 12N10P | 0.928 | fine |
| 36N42P | 0.950 | the large-diameter choice (short end-turns) |
| 6N8P (fallback) | **0.000** | torque-free space heater |
| 9N12P (fallback) | 0.292 | nearly as bad, more insidiously |

Any slot count *not* in the table falls back to a round-robin phase assignment which
can be silently terrible — the winding still draws, exports, and looks gorgeous, and
produces almost no torque. **Always check kw1 after changing `n_slots` or
`pole_pairs`.** It's printed by `point`, or directly:

```bash
python -c "
from pcb_motor.design import MotorDesign
from pcb_motor.coils import winding_factor
print(winding_factor(MotorDesign(n_slots=36, pole_pairs=21)))
"
# 0.9497882858516528
```

Rule of thumb: bigger diameter → more pole pairs (pole pitch stays a few mm) → more
slots to match. 12N14P below ~70 mm OD, 36N42P around 80–100 mm.

### Sweeps and optimization (optional)

With `pip install -e ".[sweep]"` (holobench), you get interactive dashboards over any
1–3 design fields and an optuna search:

```bash
pcb-motor sweep --inputs trace_width_mm,copper_weight_oz --serve   # localhost dashboard
pcb-motor optimize --inputs trace_width_mm,n_slots --trials 100    # max continuous accel
```

Without the extra, `sweep`/`optimize` print an install hint and exit — everything else
in this guide runs on the core install. Two habits keep optimization honest: hold your
*stock* parameters fixed (the optimizer must not pick 1.37 oz copper), and re-check
kw1 and the Stage 5 gate on the "winner" — single-objective search cheerfully trades
away things it isn't scoring. Save contenders as separate sessions and
`pcb-motor compare pancake80 <other> ...` them side by side.

## Stage 5 — The ODrive / no-choke feasibility gate

Here's the trap built into every coreless PCB motor: **no iron means almost no
inductance.** Our finished winding has L ≈ 12.6 µH per phase; hobby FOC drivers were
designed for motors with hundreds of µH to mH. A PWM voltage across a small inductance
makes a large triangular ripple current, worst at 50% duty:

```
ripple_pp = v_bus / (4 · L · f_pwm)
```

For pancake80: 24 V / (4 · 12.6 µH · 48 kHz) ≈ **9.9 A peak-to-peak** — on a motor
whose continuous rating is 1.0 A. That ripple doesn't make torque; it makes copper
heat, eddy loss, and driver stress. The evaluator gates this against your budget
(`drive_ripple_frac`, default 30% of I_cont) and prints **`Ext. L for ripple
budget`** (`l_ext_uH`): the series inductance you must add per phase to get under
budget — here ~398 µH per phase.

When the gate fails (it usually does for small air-core machines), your options, in
the order you should consider them:

1. **Accept the choke.** Three off-the-shelf shielded power inductors (rated above
   I_cont, at your ripple current) in series with the phases. It's the boring, correct
   answer; `l_ext_uH` is the shopping spec.
2. **More turns.** L grows roughly with N², R only with N — thinner traces and/or more
   layers raise L fast. You pay in Kt-per-ohm and drive voltage; re-check Stage 3.
3. **Lower bus voltage.** Ripple is linear in v_bus. A 12 V bus halves it — if speed
   × back-EMF still fits.
4. **Higher switching frequency.** Linear again; 48 kHz vs 24 kHz halves ripple.
   Driver-dependent, and switching losses climb.

A footnote that bites: **check what your driver actually switches at.** Stock
ODrive v3.6 runs f_pwm = 24 kHz; ODrive Pro and S1 can be configured up to 48 kHz.
`drive_f_pwm_hz` defaults to 24 kHz — copying an example that set 48 kHz (or the
reverse) silently halves or doubles every ripple number in the report, and with it
the choke spec. Set the frequency your hardware will really use before you believe
the gate.

And the dual-stator footnote that will save your build: the two boards **must be wired
in series, never in parallel.** Series doubles phase inductance and shares the bus
across both windings; parallel halves the inductance *and* leaves the full bus across
each — roughly **4× the effective ripple**, plus circulating current between boards
that are never perfectly identical.

## Stage 6 — Export the KiCad artifacts

Two tiers, depending on how close to ordering you are.

### Quick artwork: the `export` subcommand

Centerline `fp_line` traces of the winding — instant, great for eyeballing in KiCad,
not net-aware:

```bash
pcb-motor export --session pancake80 --single-coil --out designs/pancake80/coil.kicad_mod
# KiCad footprint written to designs/pancake80/coil.kicad_mod (single coil: 1 traces,
# 333 fp_line segments, tapered width 0.200-0.644 mm on F.Cu)
```

Drop `--single-coil` for the whole front layer.

### Production: `pcb-motor footprint` (or the `pcb_motor.kicad` API)

The one-command version builds the verified stator footprint into the session dir and
prints the report summary; `--project` also generates the KiCad project:

```bash
pcb-motor footprint --session pancake80 [--single-tooth] [--project]
# footprint written to designs/pancake80/stator_full_2side.kicad_mod
#   result           PASS
#   worst clearance  0.214 mm (need >= 0.200 mm)
#   ...
```

The same artwork is available as two Python calls when you want to inspect the
reports programmatically:

```python
from pcb_motor.session import Session
from pcb_motor.kicad import build_footprint, build_kicad_project

design = Session("pancake80").load_motor()

# Two-sided filled-copper stator footprint, clearance-verified before writing.
rep = build_footprint(design, "designs/pancake80/stator_full_2side.kicad_mod")
print(rep.passed, rep.worst_clearance_mm)   # True 0.214 (needs >= 0.200)

# KiCad project around it: stator symbol, pre-wired WYE schematic, lib tables.
proj = build_kicad_project(
    design, "designs/pancake80/kicad",
    footprint_full="designs/pancake80/stator_full_2side.kicad_mod",
)
print(proj.files)
```

(Signatures: `build_footprint(design, out_path, *, single_tooth=False, name=None,
flip=True, ...)` returns a `FootprintReport`; `build_kicad_project(design, out_dir, *,
project_name="pcb_motor_stator", footprint_full=None, footprint_single=None,
symbol_only=False, ...)` returns a `ProjectReport`. Both raise instead of writing
anything if a check fails. `build_footprint` expects `out_path`'s directory to exist.)

What `build_footprint` gives you beyond pretty spirals:

- **Two-sided filled copper**: the back layer is the *mirror* of the front about each
  coil's centre-line, so the layers are series and torque-additive. (An unmirrored
  copy looks identical and cancels its own torque — the engine's torque integrator
  verified the mirrored artwork at full torque vs exactly zero for the naive copy.)
- **Connectable terminal pads**: the winding body is deliberately netless graphic
  copper (an obstacle to the router), with real net-bearing SMD pads (`0A`, `0B`, …)
  carved out at each coil's terminals, so you can actually land traces on the motor.
- A **via stitch** linking front/back per coil, **in-footprint series bridges**
  between adjacent same-phase coils (marked as intentional net-ties for DRC), and
  everything clipped to the board disk.
- A **shapely clearance verification of the emitted text itself** before the file is
  written — `passed=False` cannot reach your fab.

`build_kicad_project` then writes a schematic where the whole motor is ONE symbol
(pin numbers = pad names), the 3-phase WYE is pre-wired, and the three phase-chain
ends come out as separate nets — precisely so two identical boards can be
series-connected externally (star the three ends on one board only). Note that the
project **vendors a copy of the footprint** into its own library,
`kicad/pcb_motor.pretty/coil_full_2side.kicad_mod` — always under that canonical
name, regardless of what the source `.kicad_mod` was called. The schematic references
the vendored copy, so the project directory is self-contained and you can move or
rename the original footprint file freely; just remember which copy KiCad is actually
reading if you regenerate one and not the other.

Two practical notes from the trenches:

- Design with `tapered_traces=true` before exporting: the production footprint always
  emits the tapered-wedge winding, so an untapered design's simulation won't match
  its own artwork (different turn counts).
- The stitch cluster needs physical room between the innermost radials. Our first
  pancake80 attempt at `r_inner_m=16e-3` failed loudly — `FootprintError: no stitch
  via fits between the innermost radials on both layers` — and moving to 18 mm fixed
  it. The builder refuses rather than emitting an unbuildable board; believe it.

### Board + Gerbers: `pcb-motor board`

The footprint and project are the pieces; `board` assembles the whole board and, with
`--gerbers`, the fab package:

```text
pcb-motor board --session pancake80 --gerbers
# board written to designs/pancake80/kicad_board (PASS)
# SUMMARY: PASS  (12 files, zip pcb_motor_stator_gerbers.zip)  kicad-cli 9.0.7
```

`build_board(design, out_dir)` (in `pcb_motor.kicad`) wraps the filled-copper footprint
in a complete `.kicad_pcb` — board outline, bore, mounting holes, and the WYE nets bound
to the terminal pads — reusing the project scaffolding from `build_kicad_project`.
`export_gerbers(pcb_path)` then runs `kicad-cli` to plot the standard 2-layer Gerber set
(copper, mask, silkscreen, paste, edge cuts) plus an Excellon drill file and zips it.

Two things to know:

- **Gerbers need `kicad-cli` (KiCad ≥ 7)** on the machine — a native install, or a
  Windows KiCad reachable from WSL (both auto-detected; or pass `--kicad-cli`). Without
  it the `.kicad_pcb` is still written and the Gerber step is skipped with a clear
  message; open the board in KiCad and File→Plot by hand.
- **The general board leaves the phase interconnect as a ratsnest.** The coil copper is
  netless graphic (it plots fine — the board is manufacturable — but KiCad can't trace a
  coil end-to-end, so the board is not connectivity-DRC-clean), and only the
  adjacent-coil series bridges are copper. The cross-ring joins that chain each phase are
  declared as nets with no track copper: KiCad shows a ratsnest for you to route. That
  final interconnect routing is the one manual step this workflow leaves to you.

The exception is a session that ships a **verbatim routed footprint** (e.g. the
committed `dualstator90-12n14p`): there `board` rebuilds the fully-routed board — every coil link,
WYE star and phase lead already copper — coordinate-for-coordinate identical to the board
that was actually fabricated (`examples/dualstator90-12n14p/fabricated/`), and its Gerbers match
layer-for-layer. That is the reference the general path is measured against.

## Stage 7 — Fab and build notes

### Ordering the boards

Full numbers with sources in [jlc_design_rules.md](jlc_design_rules.md); the short
version for JLCPCB standard process:

| Rule | 1 oz | 2 oz |
|---|---|---|
| Min trace / space | 0.127 mm (5 mil) | 0.20 mm (8 mil) |
| Via | 0.30 mm drill / 0.60 mm pad | same |
| Pad ≥ drill + 0.3 mm | yes | yes |

Order **two identical boards** (you'll get five; the spares are for the solder-braid
incident). Standard FR4, your `board_thickness_m` (0.8 mm here), copper weight as
designed. Run the fab's instant-quote DRC — vendor capabilities drift, and this table
was compiled mid-2026.

### Magnets

- **Arc segments** (`magnet_topology="arc"`) give the best fill but are usually a
  custom/AliExpress-lottery item. Match `pole_coverage` to what you actually buy.
- **Round discs** (`magnet_topology="round"`) are the buy-it-today option: two
  concentric rings of stock discs (e.g. Ø15 outer + Ø8 inner per pole, both polarized
  through-thickness). The model knows this topology — simulate what you'll build,
  don't hand-wave the substitution.
- Buy ~20% spares. NdFeB is brittle, and assembly involves tweezers, adrenaline, and
  a floor.

### Rotor carrier and assembly

- Print a carrier with pockets ~0.1 mm over magnet size; magnets go in with CA glue,
  **alternating polarity** — mark polarity with a sharpie *before* gluing, and check
  each one against its neighbor (they'll tell you: repulsion is correct).
- **Check the wall between adjacent pockets is printable.** The model knows fields,
  not printers: it will cheerfully reward a disc packing that leaves 0.16 mm of
  "wall" between round magnets. Practical minimums: **~0.8 mm for FDM**, **~0.3 mm
  for resin**. If your best packing is tighter than that, leave the pockets
  open-walled (merge them into a slot, or cut the inter-pocket wall away entirely) —
  adjacent same-ring discs repel each other, and that repulsion holds each disc
  against its pocket rim while the glue cures.
- The dual-stator sandwich is friendly to assemble: there's no iron anywhere, so the
  magnet ring isn't yanked toward the boards — handling is easy. Keep steel tools and
  other magnets clear; the ring is still very much a magnet.
- **Wire the two stators in series** (Stage 5 says why; the schematic's separate
  chain-end nets exist exactly for this). Star the three phase ends on ONE board only.
- The air gap is the whole ballgame: shim to your `air_gap_m` per side and measure it.
  Every 0.1 mm you sag costs field — and it's the first place to look when measured
  Kt comes in under prediction.
- If you use the `rotor_sides=2` dual-rotor variant instead: the two magnet plates
  attract each other **through** the stator with real force (tens of N for these
  sizes). The model prints a warning, not a number — size the hub, spacer, and an
  assembly jig for it, and never let the plates snap together over your fingers.

### Then measure

Spin it with your driver, measure Kt (torque arm or back-EMF at known speed) and
phase R. Expect agreement to a few tens of percent — see
[physics.md](physics.md) for exactly which corners the model cuts and which
measurement usually explains the gap (it's the air gap).

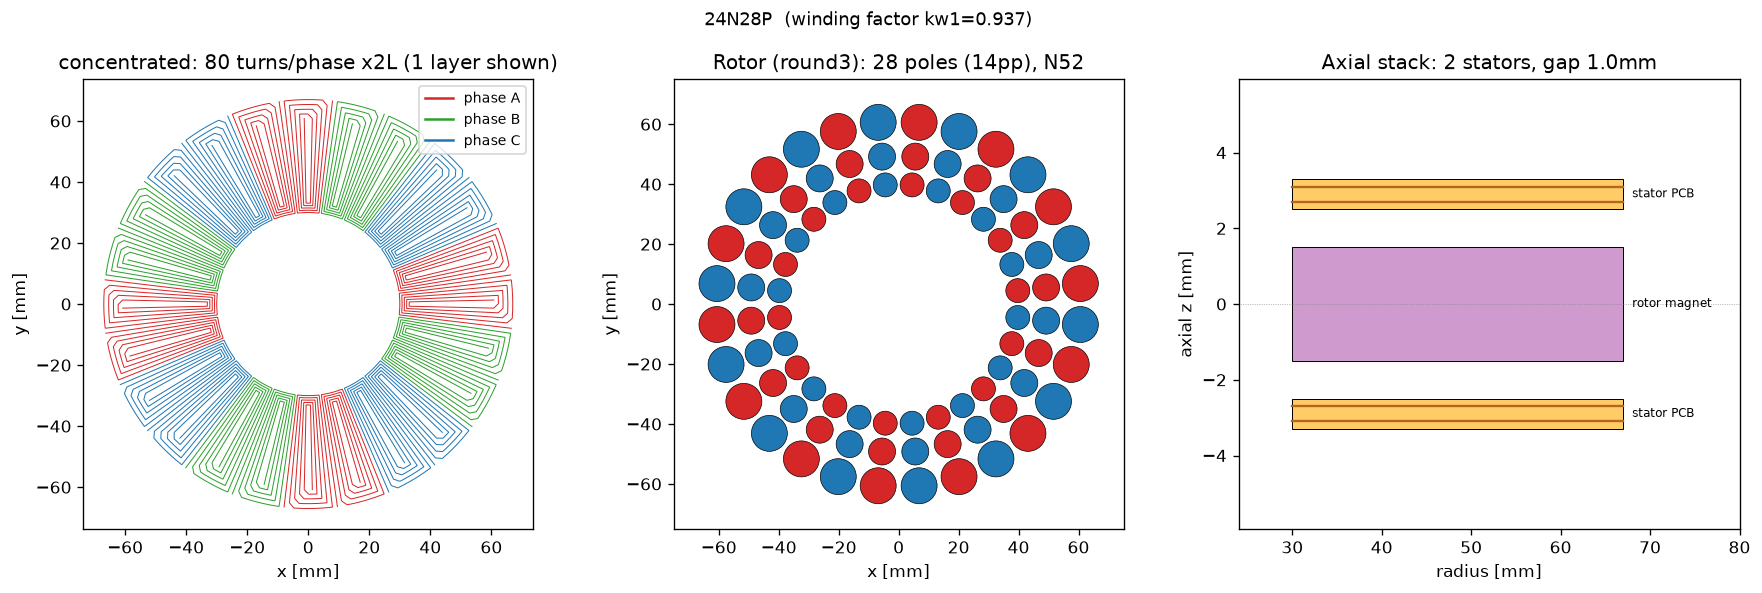
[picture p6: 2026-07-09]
examples/dualstator140-24n28p/setup.png

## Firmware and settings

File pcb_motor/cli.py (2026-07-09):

"""pcb-motor command-line interface.

    pcb-motor new          --session NAME [--set field=value ...]
    pcb-motor fields       (grouped listing of every settable MotorDesign field)
    pcb-motor point        [--session NAME] [--set field=value ...]
    pcb-motor report       [--session NAME | --set ...]
    pcb-motor showcase     [--session NAME] [--sweep 0.2,0.3,0.5] [--out page.html]
    pcb-motor datasheet    [--session NAME | --set ...]
    pcb-motor compare      NAME1 NAME2 ...
    pcb-motor footprint    --session NAME [--single-tooth] [--project]
    pcb-motor sweep        --inputs trace_width_mm,trace_space_mm [--serve]
    pcb-motor optimize     [--inputs ...] [--trials 100]

(Equivalently ``python -m pcb_motor <subcommand>``.)

``new``, ``fields``, ``point``, ``report``, ``datasheet``, ``compare`` and
``footprint`` run the pure simulator (no bencher needed). ``sweep`` /
``optimize`` need holobench (``pip install "pcb-motor[sweep]"``).
"""

from __future__ import annotations

import argparse
import dataclasses
import sys

from .design import MotorDesign
from .evaluate import evaluate_design


def _apply_overrides(design: MotorDesign, sets: list[str]) -> MotorDesign:
    """Apply ``field=value`` overrides (SI field names on MotorDesign)."""
    valid = {f.name: f.type for f in dataclasses.fields(MotorDesign)}
    for item in sets:
        if "=" not in item:
            raise SystemExit(f"--set expects field=value, got {item!r}")
        key, val = item.split("=", 1)
        key = key.strip()
        if key not in valid:
            raise SystemExit(f"unknown field {key!r}; choose from {sorted(valid)}")
        cur = getattr(design, key)
        if isinstance(cur, bool):
            newv = val.strip().lower() in ("1", "true", "yes", "on")
        elif isinstance(cur, int):
            newv = int(round(float(val)))
        elif isinstance(cur, float):
            newv = float(val)
        else:
            newv = val.strip()
        setattr(design, key, newv)
    return design


def _print_point(design: MotorDesign) -> None:
    r = evaluate_design(design)
    print(f"pcb-motor point  [{design.winding_topology}, {design.pole_pairs}pp, "
          f"{design.magnet_grade}, {design.n_stators} stator(s)]")
    print("-" * 56)
    rows = [
        ("Continuous acceleration", "accel_cont_rad_s2", "rad/s^2"),
        ("Continuous torque", "tau_cont_mNm", "mNm"),
        ("Kt (torque constant)", "kt_mNm_per_A", "mNm/A"),
        ("Continuous current", "i_cont_A", "A"),
        ("Mean airgap |Bz|", "b_gap_mean_T", "T"),
        ("Peak airgap |Bz|", "b_gap_peak_T", "T"),
        ("Phase resistance (20C)", "r_phase_20c_ohm", "ohm"),
        ("Rotor inertia J", "j_rotor_kgm2", "kg*m^2"),
        ("Total inertia J", "j_total_kgm2", "kg*m^2"),
        ("Turns / phase / layer-set", "n_turns", ""),
        ("Copper mass", "copper_mass_g", "g"),
        ("Current density", "current_density_A_mm2", "A/mm^2"),
        ("Drive voltage (cont)", "v_drive_cont_V", "V"),
        ("Airgap shear", "shear_stress_kPa", "kPa"),
        ("Phase inductance (air-core)", "l_phase_uH", "uH"),
        ("PWM ripple @bus/fsw", "pwm_ripple_A_pp", "A pp"),
        ("Ext. L for ripple budget", "l_ext_uH", "uH"),
        ("Eddy loss @ref speed", "eddy_loss_W_ref", "W"),
        ("Iron plate pull (per side)", "plate_pull_N", "N"),
        ("Torque density", "torque_density_Nm_kg", "Nm/kg"),
        ("End-turn fraction", "end_turn_fraction", ""),
        ("Winding factor kw1", "winding_factor", ""),
        ("Winding utilisation", "winding_utilisation", ""),
    ]
    for label, key, unit in rows:
        print(f"  {label:28s} {r[key]:12.4g} {unit}")
    if r["warnings"]:
        print()
        print("!" * 56)
        print(f"WARNINGS ({len(r['warnings'])}):")
        for w in r["warnings"]:
            print(f"  ! {w}")
        print("!" * 56)


def _field_docs() -> list[tuple[str, list[tuple[str, str]]]]:
    """Grouped ``(group_title, [(field_name, comment), ...])`` for MotorDesign.

    The inline comments in ``design.py`` are the source of truth for what each
    field means, so this parses the class source: ``# --- group ---`` headers
    start a group, a field's trailing ``# comment`` documents it, and deeper-
    indented comment-only lines continue the previous field's comment.
    Standalone 4-space comments become sub-notes within the group.
    """
    import inspect
    import re

    src = inspect.getsource(MotorDesign)
    groups: list[tuple[str, list[tuple[str, str]]]] = []
    cur: list[tuple[str, str]] = []
    title = "fields"
    last_field: int | None = None                    # index into cur

    field_re = re.compile(r"^    (\w+)\s*:\s*[^=]+=\s*(.+)$")
    group_re = re.compile(r"^\s*#\s*-{2,}\s*(.+?)\s*-{2,}\s*$")
    note_re = re.compile(r"^    #\s?(.*)$")
    cont_re = re.compile(r"^\s{5,}#\s?(.*)$")

    for line in src.splitlines():
        if line.lstrip().startswith("def "):
            break                                    # end of the field block
        m = group_re.match(line)
        if m:
            if cur:
                groups.append((title, cur))
            title, cur, last_field = m.group(1), [], None
            continue
        m = field_re.match(line)
        if m:
            name, rest = m.group(1), m.group(2)
            comment = rest.partition("#")[2].strip()
            cur.append((name, comment))
            last_field = len(cur) - 1
            continue
        m = cont_re.match(line)
        if m and last_field is not None:
            name, comment = cur[last_field]
            cur[last_field] = (name, (comment + " " + m.group(1).strip()).strip())
            continue
        m = note_re.match(line)
        if m and m.group(1).strip():
            cur.append(("", m.group(1).strip()))     # sub-note within the group
            last_field = None
    if cur:
        groups.append((title, cur))
    return groups


def _print_fields() -> None:
    """``pcb-motor fields``: every settable field, grouped, with defaults."""
    defaults = {f.name: getattr(MotorDesign(), f.name)
                for f in dataclasses.fields(MotorDesign)}
    print("MotorDesign fields -- settable with --set name=value "
          "(SI units unless the comment says otherwise)")
    for title, entries in _field_docs():
        print(f"\n{title}")
        for name, comment in entries:
            if not name:                             # group sub-note
                print(f"  -- {comment}")
                continue
            dflt = defaults.get(name, "?")
            dflt_s = repr(dflt) if isinstance(dflt, str) else f"{dflt:g}" \
                if isinstance(dflt, float) else str(dflt)
            line = f"  {name:22s} = {dflt_s:<14s}"
            print(f"{line} {comment}".rstrip())


def _design_for(args):
    """Build a ``MotorDesign`` from ``--session`` (if given) plus ``--set`` overrides.

    A session loads the saved motor as the base; ``--set`` overrides still apply on
    top, so you can tweak a saved design without re-saving it. Without a session it
    starts from ``MotorDesign()`` defaults (the original behaviour).
    """
    base = MotorDesign()
    if getattr(args, "session", None):
        from . import session as sessions
        s = sessions.Session(args.session, root=args.root)
        if not s.exists():
            raise SystemExit(
                f"session {args.session!r} has no saved motor under {args.root}/"
            )
        base = s.load_motor()
    return _apply_overrides(base, args.sets)


def _resolve_design(args):
    """Source a (design, session) pair for report/datasheet.

    A ``--session`` loads the saved motor; otherwise the design is
    ``MotorDesign()`` with ``--set`` overrides and there is no session.
    """
    from . import session as sessions
    session = None
    if getattr(args, "session", None):
        session = sessions.Session(args.session, root=args.root)
        if not session.exists():
            raise SystemExit(
                f"session {args.session!r} has no saved motor; "
                f"run 'pcb-motor new --session {args.session}' first"
            )
        design = session.load_motor()
    else:
        design = _apply_overrides(MotorDesign(), args.sets)
    return design, session


def main(argv=None) -> int:
    argv = list(sys.argv[1:] if argv is None else argv)
    p = argparse.ArgumentParser(prog="pcb-motor", description=__doc__)
    sub = p.add_subparsers(dest="cmd", required=True)

    pp = sub.add_parser("point", help="evaluate one design and print results")
    pp.add_argument("--set", action="append", default=[], dest="sets",
                    help="override a MotorDesign field, e.g. --set trace_width_m=2e-4")
    pp.add_argument("--session", help="base the design on designs/<name>/")
    pp.add_argument("--root", default="designs")

    pc = sub.add_parser("config", help="save a setup figure (winding + rotor + stack)")
    pc.add_argument("--set", action="append", default=[], dest="sets")
    pc.add_argument("--out", default="setup.png", help="output PNG path")
    pc.add_argument("--session", help="base the design on designs/<name>/")
    pc.add_argument("--root", default="designs")

    pe = sub.add_parser("export", help="export coil geometry as a KiCad footprint (.kicad_mod)")
    pe.add_argument("--set", action="append", default=[], dest="sets",
                    help="override a MotorDesign field, e.g. --set corner_radius_m=2e-4")
    pe.add_argument("--out", default="coil.kicad_mod", help="output .kicad_mod path")
    pe.add_argument("--layer", default="F.Cu", help="KiCad copper layer name")
    pe.add_argument("--single-coil", action="store_true",
                    help="export one tooth/coil (first angular sector) instead of the whole layer")
    pe.add_argument("--session", help="base the design on designs/<name>/")
    pe.add_argument("--root", default="designs")

    pw = sub.add_parser("sweep", help="bencher sweep dashboard (needs holobench)")
    pw.add_argument("--inputs", required=True, help="1-3 sweep axes, comma-separated")
    pw.add_argument("--results", help="result vars (comma-separated; default headline set)")
    pw.add_argument("--out", default="dashboard", help="output directory")
    pw.add_argument("--set", action="append", default=[], dest="sets",
                    help="hold a sweep input fixed, e.g. --set r_outer_mm=45 (display units)")
    pw.add_argument("--serve", action="store_true", help="serve live instead of saving")
    pw.add_argument("--port", type=int, default=9001)
    pw.add_argument("--no-cache", action="store_true")

    po = sub.add_parser("optimize", help="maximise continuous acceleration (needs holobench)")
    po.add_argument("--inputs", help="design axes to optimise (comma-separated)")
    po.add_argument("--trials", type=int, default=100)

    pf = sub.add_parser("new",
                        help="seed a new design session from defaults + --set overrides")
    pf.add_argument("--session", required=True,
                    help="save the motor into designs/<name>/")
    pf.add_argument("--set", action="append", default=[], dest="sets",
                    help="set a MotorDesign field, e.g. --set pole_pairs=7 --set n_slots=12")
    pf.add_argument("--root", default="designs")

    sub.add_parser("fields",
                   help="list every settable MotorDesign field with default and meaning")

    pfp = sub.add_parser(
        "footprint",
        help="build the production two-sided filled-copper stator footprint "
             "(net-bearing pads, verified clearances) into the session dir")
    pfp.add_argument("--session", required=True,
                     help="session under designs/<name>/ to build the footprint for")
    pfp.add_argument("--set", action="append", default=[], dest="sets",
                     help="override a MotorDesign field for this build only")
    pfp.add_argument("--single-tooth", action="store_true",
                     help="emit only the base coil (tooth 0) instead of the full stator")
    pfp.add_argument("--project", action="store_true",
                     help="also generate the KiCad project (stator symbol + WYE "
                          "schematic + library tables) into designs/<name>/kicad/")
    pfp.add_argument("--resolution-mm", type=float, default=0.2,
                     help="artwork buffering resolution [mm]; coarser = faster "
                          "(default 0.2, production quality)")
    pfp.add_argument("--root", default="designs")

    pbd = sub.add_parser(
        "board",
        help="build the full KiCad board (.kicad_pcb) for a session and, with "
             "--gerbers, export a fab-ready gerber+drill zip")
    pbd.add_argument("--session", required=True,
                     help="session under designs/<name>/ to build the board for")
    pbd.add_argument("--set", action="append", default=[], dest="sets",
                     help="override a MotorDesign field for this build only")
    pbd.add_argument("--gerbers", action="store_true",
                     help="also export fab-ready gerbers+drill (zip) via kicad-cli")
    pbd.add_argument("--kicad-cli", default=None, dest="kicad_cli",
                     help="path to kicad-cli (default: auto-detect, including "
                          "a Windows KiCad install reachable from WSL)")
    pbd.add_argument("--root", default="designs")

    pr = sub.add_parser("report", help="write a combined HTML design report")
    pr.add_argument("--set", action="append", default=[], dest="sets")
    pr.add_argument("--session", help="load the design from designs/<name>/")
    pr.add_argument("--out", help="output HTML path (default: session dir or design_report.html)")
    pr.add_argument("--name", help="report title")
    pr.add_argument("--rich", action="store_true",
                    help="also embed the Biot-Savart rotating-field & torque figures (slow, ~1 min)")
    pr.add_argument("--root", default="designs")

    pds = sub.add_parser("datasheet", help="write a Markdown key-parameters datasheet")
    pds.add_argument("--set", action="append", default=[], dest="sets")
    pds.add_argument("--session", help="load the design from designs/<name>/")
    pds.add_argument("--out", help="output Markdown path (default: session dir or datasheet.md)")
    pds.add_argument("--name", help="datasheet title")
    pds.add_argument("--root", default="designs")

    psc = sub.add_parser(
        "showcase",
        help="build the self-contained narrative showcase page (spinning motor, "
             "copper viewer, exploded stack, trade-off charts) for a design")
    psc.add_argument("--set", action="append", default=[], dest="sets")
    psc.add_argument("--session", help="load the design from designs/<name>/")
    psc.add_argument("--out",
                     help="output HTML path (default: designs/<name>/report.html)")
    psc.add_argument("--name", help="page title (default: session name)")
    psc.add_argument("--narrative",
                     help="narrative markdown file (default: the session's "
                          "narrative.md if present; missing sections are "
                          "auto-generated)")
    psc.add_argument("--sweep",
                     help="comma-separated trace widths in mm to re-evaluate for "
                          "the design-hunt charts (slow: one full engine run per "
                          "width), e.g. --sweep 0.15,0.2,0.3,0.5")
    psc.add_argument("--draft", action="store_true",
                     help="lower-fidelity torque/field sampling for quick previews")
    psc.add_argument("--root", default="designs")

    pcmp = sub.add_parser("compare", help="compare saved design sessions side by side")
    pcmp.add_argument("names", nargs="+", help="session names under designs/")
    pcmp.add_argument("--out", help="write the comparison table to this Markdown file")
    pcmp.add_argument("--root", default="designs")

    args = p.parse_args(argv)

    if args.cmd == "point":
        design = _design_for(args)
        _print_point(design)
        return 0

    if args.cmd == "config":
        from . import viz
        design = _design_for(args)
        fig = viz.plot_setup(design)
        fig.savefig(args.out, dpi=120, bbox_inches="tight")
        print(f"setup figure written to {args.out}")
        return 0

    if args.cmd == "export":
        from .kicad import export as K
        from .coils import build_coil
        design = _design_for(args)
        geo = build_coil(design)
        polylines = K._layer0_polylines(geo.polylines)
        if args.single_coil:
            polylines = K._first_sector_polylines(polylines, design.n_slots)
        if not polylines:
            print("no polylines to export")
            return 2
        width_fn = None
        width_note = f"width {design.trace_width_m*1e3:.3f} mm"
        if getattr(design, "tapered_traces", False):
            from .coil_spiral import trace_width_at
            width_fn = lambda r: trace_width_at(design, r)
            w_out = float(trace_width_at(design, design.r_outer_m))
            width_note = (f"tapered width {design.trace_width_m*1e3:.3f}"
                          f"-{w_out*1e3:.3f} mm")
        n_lines = K.write_coil_kicad_mod(
            args.out, polylines, design.trace_width_m, layer=args.layer,
            name=f"pcb_motor_{design.winding_topology}", width_fn=width_fn,
        )
        scope = "single coil" if args.single_coil else "front copper layer"
        print(f"KiCad footprint written to {args.out} "
              f"({scope}: {len(polylines)} traces, {n_lines} fp_line segments, "
              f"{width_note} on {args.layer})")
        return 0

    if args.cmd in ("sweep", "optimize"):
        try:
            from . import sweep as S
        except ImportError as exc:
            print(exc)
            return 2
        inputs = [s.strip() for s in (args.inputs or "").split(",") if s.strip()]
        if args.cmd == "sweep":
            results = ([s.strip() for s in args.results.split(",") if s.strip()]
                       if args.results else None)
            const = {}
            for item in args.sets:
                k, _, v = item.partition("=")
                v = v.strip()
                if v.lower() in ("true", "false", "yes", "no", "on", "off"):
                    const[k.strip()] = v.lower() in ("true", "yes", "on")
                    continue
                try:
                    const[k.strip()] = float(v)
                except ValueError:
                    const[k.strip()] = v
            path = S.build_dashboard(
                input_vars=inputs, result_vars=results, out_dir=args.out,
                serve=args.serve, port=args.port, cache=not args.no_cache, const=const,
            )
            if path:
                print(f"dashboard written to {path}")
            return 0
        else:
            res = S.optimize(input_vars=inputs or None, n_trials=args.trials)
            print("optimization complete:", res)
            return 0

    if args.cmd == "new":
        from . import session as sessions
        design = _apply_overrides(MotorDesign(), args.sets)
        s = sessions.Session(args.session, root=args.root)
        s.save_motor(design)
        print(f"session saved to {s.dir}")
        if not s.requirements_yaml.exists():
            s.save_requirements(sessions.requirements_skeleton(args.session))
            print(f"requirements skeleton written to {s.requirements_yaml} "
                  "-- fill in your targets (torque, speed, voltage, envelope, duty)")
        _print_point(design)
        return 0

    if args.cmd == "fields":
        _print_fields()
        return 0

    if args.cmd == "footprint":
        from . import session as sessions
        from .kicad import FootprintError, build_footprint

        s = sessions.Session(args.session, root=args.root)
        if not s.exists():
            raise SystemExit(
                f"session {args.session!r} has no saved motor; "
                f"run 'pcb-motor new --session {args.session}' first"
            )
        design = _apply_overrides(s.load_motor(), args.sets)
        fname = ("stator_single_2side.kicad_mod" if args.single_tooth
                 else "stator_full_2side.kicad_mod")
        out = s.dir / fname
        try:
            rep = build_footprint(design, str(out),
                                  single_tooth=args.single_tooth,
                                  resolution_m=args.resolution_mm * 1e-3)
        except FootprintError as exc:
            print(f"FOOTPRINT FAILED: {exc}", file=sys.stderr)
            return 2
        print(f"footprint written to {out}")
        print(f"  result           {'PASS' if rep.passed else 'FAIL'}")
        print(f"  worst clearance  {rep.worst_clearance_mm:.3f} mm "
              f"(need >= {rep.clearance_needed_mm:.3f} mm)")
        print(f"  coils            {rep.n_coils} x {rep.turns_per_coil} turns")
        def _pad_key(nm: str):
            digits = "".join(ch for ch in nm if ch.isdigit())
            return (int(digits) if digits else 0, nm)

        pads_ordered = sorted(rep.pad_names, key=_pad_key)
        print(f"  pads             {len(rep.pad_names)} "
              f"({pads_ordered[0]} .. {pads_ordered[-1]})")
        print(f"  bridges          {rep.n_bridges}")
        print(f"  vias per coil    {rep.n_vias_per_coil} "
              f"(stitch track {rep.conn_track_w_mm:.2f} mm)")
        for n in rep.notes:
            print(f"  note: {n}")
        if args.project:
            from .kicad import build_kicad_project
            from .kicad.project import ProjectError
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

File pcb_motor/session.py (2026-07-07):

"""Workflow glue tying the engine into a named motor-design session.

This is the connective tissue the conversational design workflow needs; it adds
no physics. Two pieces:

- ``Session`` -- a ``designs/<name>/`` directory holding the motor JSON, an
  optional requirements YAML, and the generated artifacts (setup PNG, KiCad
  footprint, HTML report, datasheet). Gives the workflow durable state across
  turns and lets you keep several named candidates side by side.
- ``compare`` / ``datasheet`` -- render the headline metrics of one or several
  designs as Markdown (the comparison table and the final key-parameters sheet).
"""

from __future__ import annotations

import dataclasses
import json
from pathlib import Path

from .design import MotorDesign
from .evaluate import evaluate_design

DEFAULT_ROOT = "designs"

REQUIREMENTS_SKELETON = """\
# Requirements for design session '{name}'.
# Fill in your targets and constraints; delete keys that do not apply.
# Free-form YAML: the file lives beside motor.json so the requirements and the
# design evolve together (Stage 1 of the design guide).

torque_mNm:            # continuous torque target [mNm]
speed_rev_s:           # operating speed [rev/s]
voltage_V:             # DC bus voltage available [V] (also set drive_v_bus)
envelope_od_mm:        # max stator outer diameter [mm]
envelope_axial_mm:     # max axial stack height [mm]
duty:                  # thermal context, e.g. "continuous" or "30% for 10 s bursts"
"""


def requirements_skeleton(name: str) -> str:
    """A commented requirements.yaml starter for a new session."""
    return REQUIREMENTS_SKELETON.format(name=name)


# --------------------------------------------------------------------------- #
# Session: a named design on disk
# --------------------------------------------------------------------------- #
class Session:
    """A ``designs/<name>/`` directory for one candidate design.

    Holds the motor design (``motor.json``), an optional requirements file
    (``requirements.yaml``), and the generated artifacts (setup PNG, KiCad
    footprint, HTML report, datasheet). All paths are derived; nothing is
    written until you call a ``save_*`` method.
    """

    def __init__(self, name: str, root: str | Path = DEFAULT_ROOT) -> None:
        self.name = name
        self.root = Path(root)
        self.dir = self.root / name

    # -- derived paths --
    @property
    def motor_json(self) -> Path:
        return self.dir / "motor.json"

    @property
    def requirements_yaml(self) -> Path:
        return self.dir / "requirements.yaml"

    @property
    def setup_png(self) -> Path:
        return self.dir / "setup.png"

    @property
    def kicad_mod(self) -> Path:
        return self.dir / "coil.kicad_mod"

    @property
    def report_html(self) -> Path:
        return self.dir / "design_report.html"

    @property
    def datasheet_md(self) -> Path:
        return self.dir / "datasheet.md"

    # -- persistence --
    def save_motor(self, design: MotorDesign) -> Path:
        self.dir.mkdir(parents=True, exist_ok=True)
        self.motor_json.write_text(
            json.dumps(dataclasses.asdict(design), indent=2), encoding="utf-8"
        )
        return self.motor_json

    def load_motor(self) -> MotorDesign:
        data = json.loads(self.motor_json.read_text(encoding="utf-8"))
        valid = {f.name for f in dataclasses.fields(MotorDesign)}
        return MotorDesign(**{k: v for k, v in data.items() if k in valid})

    def save_requirements(self, text: str) -> Path:
        """Persist a free-form requirements YAML/Markdown blob alongside the motor."""
        self.dir.mkdir(parents=True, exist_ok=True)
        self.requirements_yaml.write_text(text, encoding="utf-8")
        return self.requirements_yaml

    def load_requirements(self) -> str | None:
        """Return the saved requirements text if present, else ``None``."""
        if not self.requirements_yaml.exists():
            return None
        return self.requirements_yaml.read_text(encoding="utf-8")

    def exists(self) -> bool:
        return self.motor_json.exists()

    @classmethod
    def list_all(cls, root: str | Path = DEFAULT_ROOT) -> list["Session"]:
        """All sessions under ``root`` that have a saved motor, sorted by name."""
        base = Path(root)
        if not base.is_dir():
            return []
        out = [cls(p.name, root) for p in sorted(base.iterdir()) if p.is_dir()]
        return [s for s in out if s.exists()]


# --------------------------------------------------------------------------- #
# Headline metrics, shared by the datasheet and the comparison table
# --------------------------------------------------------------------------- #
def _fmt(v: float, nd: int = 4) -> str:
    return f"{v:.{nd}g}"


def _trace_row(design: MotorDesign) -> str:
    """Trace/space cell; tapered windings show the ID->OD width range."""
    ts_mm = design.trace_space_m * 1e3
    if getattr(design, "tapered_traces", False):
        from .coil_spiral import trace_width_at

        w_out = float(trace_width_at(design, design.r_outer_m)) * 1e3
        return (f"{design.trace_width_m*1e3:.3f}-{w_out:.3f} (tapered) "
                f"/ {ts_mm:.3f} mm")
    return f"{design.trace_width_m*1e3:.3f} / {ts_mm:.3f} mm"


def _magnet_row(design: MotorDesign) -> str:
    """Magnet cell. ``pole_coverage`` is an arc-rotor parameter only (round
    disc rotors ignore it entirely, in both the field and the inertia models),
    so round topologies show the disc/ring geometry instead of a coverage
    figure that has no effect."""
    from .magnets import is_round

    head = (f"{design.magnet_grade}, {design.magnet_topology}, "
            f"{design.pole_pairs} pole-pairs, {design.magnet_thickness_m*1e3:.1f} mm")
    if is_round(design.magnet_topology):
        from .magnets import active_rings

        rings = ", ".join(
            f"D{disc_d*1e3:g} discs @ r={ring_r*1e3:g} mm"
            for ring_r, disc_d in active_rings(design.rotor())
        )
        return f"{head}, {rings}"
    return f"{head}, {design.pole_coverage*100:.0f}% coverage"


def _ripple_gate_row(design: MotorDesign, r: dict) -> tuple[str, str]:
    """Explicit PASS/FAIL for the PWM-ripple (choke) gate -- design guide
    Stage 5. PASS means bare-winding worst-case ripple fits the budget."""
    budget = design.drive_ripple_frac * r["i_cont_A"]
    ripple = r["pwm_ripple_A_pp"]
    if ripple <= budget:
        verdict = (f"PASS ({_fmt(ripple)} A pp <= {_fmt(budget)} A budget)")
    else:
        verdict = (f"FAIL ({_fmt(ripple)} A pp > {_fmt(budget)} A budget, "
                   f"{ripple/budget:.0f}x -- needs ~{_fmt(r['l_ext_uH'])} uH/phase "
                   "external L)")
    return ("PWM ripple gate", verdict)
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

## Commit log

2026-07-07 Port core physics engine from motorsim (verified, 34 tests)
    Biot-Savart field solver, magnet bound-current model, Kt/torque via 3-phase
    commutation, inductance + worst-case PWM ripple (ODrive gate), thermal limit,
    inertia, back-iron images, evaluate_design orchestrator. Vendored
    biot_savart_v4_3 oracle dropped; field.py validated against closed-form loop.
    Claude-Session: https://claude.ai/code/session_01Y2YW46VqzQtnSmihdnMbDJ
2026-07-07 Port coil geometry: windings, spirals, star-of-slots layouts
    Adds the 36-slot/42-pole layout (12N14P pattern tiled 3x with alternating
    polarity) — the round-robin fallback silently gives kw1~0 for 36N42P; a
    winding-factor test locks kw1=0.933 at full pitch. Two kicad-export tests
    land with the kicad subpackage (next commit).
    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
2026-07-07 Add pcb_motor.kicad: footprint + stator project generators as a real API
    Production two-sided filled-copper footprint (mirrored B.Cu, net-bearing
    terminal pads, net ties, decimate/disk-clip) and stator symbol/schematic
    project, both generalized from the 12-coil scripts to any n_slots via the
    star-of-slots layout, gated on shapely clearance verify (raise, don't emit).
    All KiCad writers CRLF.
    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
2026-07-07 Port workflow layer: CLI, sessions, HTML report, figures, sweep
    pcb-motor CLI (new/point/config/export/sweep/optimize/report/datasheet/
    compare) with per-design session dirs under designs/. Sweep/optimize needs
    the optional [sweep] extra and fails with a clear message without it.
    Model-honesty footer set to ~±30% on absolute torque.
    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
    [cli.py, session.py]
2026-07-07 Add dual-rotor sandwich topology (rotor_sides=2)
    Second magnet plane mirrored at 2*stator_z with same current sense
    (attracting arrangement, fields add): exactly 2x Bz at the board, ~2x Kt.
    Requires n_stators=1 and no back iron (validated). Rotor inertia doubles.
    Stack drawing now matches the real configuration (fixes two-boards-for-
    n_stators=1 bug). Rotor-rotor axial pull flagged in warnings, not modelled.
    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
2026-07-07 Center copper layers on the board (layer_z_m)
    Layers were stacked from the board centre outward (layer0 at centre,
    layer1 a full thickness beyond), displacing the copper stack by t/2.
    Now layers span the board symmetrically (2 layers -> faces at +/- t/2).
    Dual/single Kt ratio is now exactly 2.0 by symmetry; absolute Kt shifts
    a few percent (more at high pole counts where the gap field decays fast).
    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
2026-07-07 Docs: README, design guide, physics notes, JLC rules, Claude skill
    End-to-end walkthrough (requirements -> seed -> iterate -> no-choke gate ->
    KiCad export -> fab), module-level physics doc with the itemized ~±30% error
    budget, and the in-repo pcb-motor-design skill so an agent can drive the
    whole process. Real generated figures, every command actually run.
    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
2026-07-07 Fix fresh-user eval friction: loud gates, CLI coverage, better errors
    - evaluate: warn loudly when PWM ripple exceeds budget (with computed choke
    spec) and on >80 A/mm2 hot necks; point/new print a warning banner
    - datasheet: ripple-gate PASS/FAIL row with full drive context; disc-ring
    description replaces meaningless 'coverage' on round rotors; turns label
    unified to 'turns / phase / layer-set'
    - CLI: new 'footprint' (production artwork + --project from a session),
    'fields' (grouped MotorDesign reference), requirements.yaml skeleton on new
    - footprint: numeric remedies in stitch-fit errors; loud note when an
    untapered design is coerced to tapered artwork
    - viz.plot_b_field: real B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
    [cli.py, session.py]
2026-07-07 Docs polish from eval friction: series totals, round rotors, real costs
    R/L documented as n_stators-series totals; round-disc rotor section with
    worked example and inert-field warnings; ODrive 24k/48k PWM footnote;
    carrier-wall buildability guidance; turn-quantization and vendored-footprint
    notes; README tour transcript refreshed against current output.
    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
2026-07-07 Add worked example: odrive80 (80mm, 42-pole, dual-stator, ODrive)
    Complete committed design session from the fresh-user eval: requirements,
    saved design, regenerated datasheet with the ripple-gate FAIL row, compare
    table, verified footprint (PASS, 0.137mm worst clearance) and KiCad project,
    and a README telling the honest story: 20.5 mNm continuous +/-30%, no-choke
    drive infeasible by 32x, ~204 uH/phase chokes required.
    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
    [motor.json, pcb_motor_stator.kicad_sch]
2026-07-08 Add showcase reports + verbatim routed-stator port
    showcase: reusable narrative HTML generator (pcb-motor showcase) — spinning
    motor+field animation, interactive copper viewer (auto-builds the production
    footprint, loud preview labelling otherwise), exploded stack, trade-off
    charts; self-contained output; reports for both examples; Pages landing.
    kicad.routed: build_routed_stator/build_routed_project ported verbatim from
    the shipped gimbal90 scripts (tabs variant incl. M3 half-holes, connector
    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
    [motor.json]
2026-07-08 gimbal90 replaces the default-machine demo; routed boards in showcase
    examples/gimbal90: the shipped 90mm board regenerated through the repo
    (fully-routed circular + tabs .kicad_mod, regression-pinned), datasheet,
    narrative, showcase report showing the routed tabs copper. Showcase parser
    now understands routed-style boards (all copper as net-bearing pads).
    Full suite: 131 passed.
    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
    [motor.json]
2026-07-08 Add Gerber/drill export module (kicad-cli shellout)
    Phase 0 of the end-to-end workflow: pcb_motor/kicad/gerbers.py exports a
    KiCad .kicad_pcb to the standard JLCPCB 2-layer Gerber set + Excellon drill
    via `kicad-cli`, zips them for the fab, and degrades gracefully to a clear
    GerberError when kicad-cli is absent (rather than a bare FileNotFoundError).
    Wired into kicad/__init__.py. Mock-based tests cover the happy path, the
    missing-cli and missing-board errors, stderr surfacing, and custom
    out-dir/zip paths -- so the suite runs with no KiCad installed.
    Claude-Session: https://claude.ai/code/session_016nY5Rn2NTaGpBBvjt3SCXb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
2026-07-08 Restyle showcase (plainer) + draw real board outline & tabs
    Phase 1: de-design the showcase to a plain, technical look and show the
    actual board shape.
    - CSS: drop the hero radial-gradient, the tooltip drop-shadow, the
    accent-coloured kicker labels, and the scroll-reveal motion. Keep the
    data-encoding palette (phases / field polarity / gate) -- those carry
    meaning in the charts.
    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
2026-07-08 Reproduce gimbal90 board -> gerbers, verified fab-equivalent
    Phase 2. `pcb-motor board --session gimbal90 --gerbers` rebuilds the exact
    fabricated routed-tabs board and exports its Gerbers.
    - cli.py: new `board` command. A session with a committed routed footprint
    (gimbal90) rebuilds its verbatim board via build_routed_project; others fall
    through to the general path (board.py, Phase 3). --gerbers exports a
    fab-ready zip via kicad-cli.
    - gerbers.py: run a Windows kicad-cli.exe from WSL (wslpath translation) so the
    pipeline works against an installed Windows KiCad; discover_kicad_cli() finds
    native or Windows KiCad; drill flag fixed to KiCad's --generate-map; gerbers
    and drill sh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
    [gimbal90_routed_tabs.kicad_pcb]
2026-07-08 Add general agent-driveable board path (board.py)
    Phase 3. build_board(design, out_dir) wraps footprint.build_footprint's
    filled-copper stator in a complete .kicad_pcb for ANY concentrated-winding
    design, so a design that isn't gimbal90 still reaches a board + gerbers
    through the same `pcb-motor board` command.
    - Reuses project._Plan for the WYE netlist and build_kicad_project for the
    sch/sym/pro/lib scaffolding; binds the terminal pads to their nets (stitch
    vias stay net 0), adds a circular Edge.Cuts + bore (+ optional mount holes),
    and copies routed.py's layer stack + pcbplotparams verbatim (local copy, so
    the fab-verified routed path is untouched).
    - Honest limits: coil copper is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
2026-07-08 Docs: technical-voice README, board+Gerber stages, CLAUDE.md, attribution
    Phase 4.
    - README rewritten in a clear, technical voice (dropped the comedic register);
    the Gerber claims are now backed by the implemented board+gerber pipeline,
    with the general path's ratsnest limitation stated honestly. Adds the
    `pcb-motor board --gerbers` step and a kicad-cli prerequisite note.
    - SKILL.md + docs/design_guide.md: new Board + Gerbers stage (build_board /
    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
2026-07-08 Add verified 24N28P winding; pre-flight hardening
    Phase 5 (pre-flight). De-overfit the winding layer and smooth the general
    path before the independent-agent eval.
    - coils._LAYOUTS[24] = _LAYOUTS[12]*2: 24N28P (24 slots, 14 pole-pairs) is now
    a verified concentrated combo (kw1 = 0.9378 measured), valid for the same
    tiling reason as 36N42P. Previously any non-{12,36} slot count fell back to
    the round-robin layout that can collapse kw1 to ~0. test_coils covers it.
    - SKILL.md: 24N28P listed among the verified slot/pole combos.
    Walked the whole general workflow on a throwaway 120 mm / 24N28P design:
    new -> point -> gate -> footprint (clearance PASS) -> board (PASS) -> gerbers
    (12-file zi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
    [test_coils.py]
2026-07-08 Publish camslider140: the independent-agent generalization eval
    Phase 6. A fresh agent -- given only a 140 mm application brief, the repo, and
    the pcb-motor-design skill, with no authoring context -- drove the whole
    workflow itself and produced this design. No files were hand-edited to make it
    work; it succeeded on the first run and needed zero tool fixes.
    It designed a genuinely new machine (24N28P, 134 mm, kw1 0.9374 -- distinct
    from gimbal90's 12N14P/90 mm), compared three pole counts, reached a
    clearance-verified footprint + complete board + fab-ready gerbers (plotted via
    the auto-detected Windows kicad-cli) + showcase, and reported the no-choke gate
    failure honestly (16x over, needs a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
    [motor.json, pcb_motor_stator.kicad_pcb, pcb_motor_stator.kicad_sch]
2026-07-08 Tidy: landing page (technical voice + camslider140), .gitignore
    Phase 7 tidy.
    - index.html: retune to the technical voice, drop the comedic lines, and add
    the camslider140 card (the independent-agent eval). gimbal90 now billed as
    "the board that was fabricated" (regenerated coordinate-identical, Gerbers
    match layer-for-layer). Claims match the implemented pipeline.
    - .gitignore: drop the redundant designs/*/... lines (the blanket designs/
    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
2026-07-09 Regenerate gimbal90 + odrive80 showcases in the plain style
    Phase 7. The published example pages predated the Phase-1 restyle; regenerate
    them so all three examples match: no gradient/shadow/motion, real board outline
    + mounting tabs in the viewer. gimbal90 now renders its real routed copper (0
    PREVIEW notices) instead of the footprint-build-preview fallback.
    Claude-Session: https://claude.ai/code/session_016nY5Rn2NTaGpBBvjt3SCXb
2026-07-09 Fix exploded-stack occlusion + back iron; add round3 magnet topology
    Exploded stack (showcase.js/css + _stack_payload):
    - Paint layers back-to-front for a from-above camera so the top of the stack
    sits in front. The collapsed/partial state previously occluded in the wrong
    order (bottom board drawn over everything), which did not read as physical.
    - Emit and render the back-iron return plates (hatched mild-steel look) when
    design.back_iron is set -- they were absent from the stack before, so you
    could not tell iron from coreless. Caption now states "Back iron: yes/none".
    - Fade leader labels in with the explode so they don't pile up while closed;
    reduced-motion users open to a separ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
    [gimbal90_routed_tabs.kicad_pcb, motor.json, pcb_motor_stator.kicad_pcb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]
2026-07-09 Rename showcases to spec-code names; regenerate with sweep + 3-ring rotor
    Rename (user request -- "axial" isn't descriptive; use the dual-stator + winding):
    - gimbal90 -> dualstator90-12n14p (the fabricated board; keeps its
    as-built gimbal90_routed_tabs filenames, byte-pinned by
    tests/test_board_fabequiv.py)
    - odrive80 -> dualstator80-36n42p
    - camslider140 -> dualstator140-24n28p
    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
    [motor.json]
2026-07-09 Refocus README on the 12N14P; enforce >=1mm magnet spacing; correct 3-ring
    Repo now leads with the fabricated 12N14P main event, not the 42-pole eval:
    - README hero + physics images regenerated from dualstator90-12n14p (were 36N42P);
    worked-examples reordered so "the board that was fabricated" is first, with the
    80/140 mm designs demoted to a labelled "Generalization evals" section.
    >=1 mm magnet-to-housing spacing:
    - Generic engine check: magnets.magnet_edge_gaps + a warning in evaluate_design
    (flags <1 mm pole-to-pole and ring-to-ring on any round rotor). Unit-tested.
    - Corrected the 140 mm 3rd ring: Ø8 (0.0 mm radial -- touching, my error) -> Ø6
    (1.0 mm radial). Torque honestly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
    [motor.json]
2026-07-09 Fix animation phase colours on the routed board (net-name, both layers)
    The hero animation tinted each coil by phase via the geometric tooth index
    (_tooth_of, centroid-angle rounding). That works for clean one-coil-per-tooth
    boards (verified: odrive/camslider colour correctly), but the fully-routed
    gimbal's copper lives in net-bearing pads whose centroids don't resolve into
    clean per-slot coils -- so phases were scrambled (blue coils bunched, sectors
    missing), which is what the 12N14P showcase showed.
    Fix: colour routed copper from the pad NET NAME (AL/AE->A, BL/BE->B, CL/CE->C),
    which is an exact phase label, and draw BOTH copper layers so the routed board
    (which splits copper front/back)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
    [showcase.py]
2026-07-09 Plainer tone (drop the "motor that is a circuit board" tagline); sensible 3-ring
    Tone: the showcase hero kicker and footer, the landing <title>/<h1>, and the
    README one-liner carried a "a motor that IS a circuit board" slogan that clashes
    with the intended plain, technical voice. Replaced with plain descriptors
    ("coreless axial-flux PCB motor" / "concept to fab-ready Gerbers"). Predates this
    work, but was re-emitted here, so cleaned up. gimbal/odrive reports spliced in
    place (left otherwise as-is); camslider re-rendered.
    Magnets: the 140 mm 3-ring rotor had a Ø6 middle ring sitting OUTSIDE the Ø8 inner
    ring -- magnets shrinking with radius, which is backwards. Re-laid the rings to step
    up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
    [motor.json]
